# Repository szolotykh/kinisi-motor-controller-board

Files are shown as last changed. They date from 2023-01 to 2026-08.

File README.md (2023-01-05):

# Kinisi Motor Controller
Kinisi motor controller is based on STM32F405 microcontroller controller. The controller can control up to 4 brushed DC motors with encoders. It offers platform obstruction which is means user doesn’t need to control each individual motor form main computer, but rather it can control up to four motors as a whole by sending high level commands like set target speed or distance for a platform.

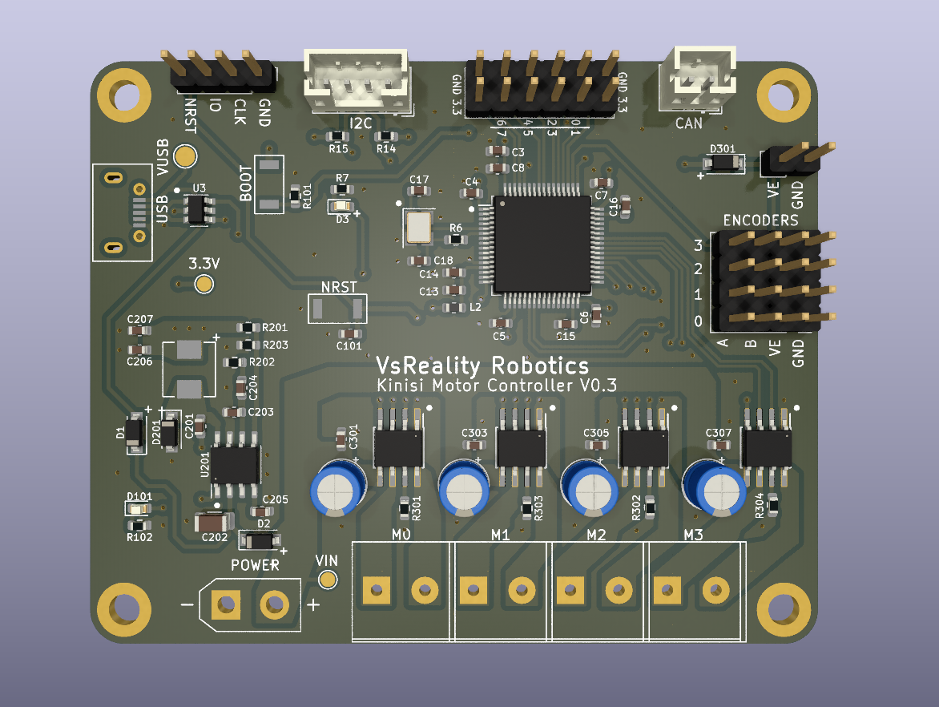
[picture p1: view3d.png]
Board 3d view


Features:
* Controls 4 motors
* Receives readings from 4 encoders
* Supports encoders with wide range of supply voltage (3.3V, 5V, custom) 

Interfaces:
* USB Serial device
* I2C
* CAN
* 4x GPIO

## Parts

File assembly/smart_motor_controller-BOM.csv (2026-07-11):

Comment | Designator | Footprint | LCSC
4u7 | C3 | Capacitor_SMD:C_0603_1608Metric | C19666
10uf | C202 | Capacitor_SMD:C_1206_3216Metric | C13585
1nF | C204 | Capacitor_SMD:C_0603_1608Metric | C340644
8.2nF | C205 | Capacitor_SMD:C_0603_1608Metric | C1322360
1u | C13,C101 | Capacitor_SMD:C_0603_1608Metric | C15849
10nf | C14,C203 | Capacitor_SMD:C_0603_1608Metric | C57112
2.2u | C15,C16 | Capacitor_SMD:C_0603_1608Metric | C23630
12p | C17,C18 | Capacitor_SMD:C_0603_1608Metric | C1642
47uF | C206,C207 | Capacitor_SMD:C_0603_1608Metric | C140782
100n | C301,C303,C305,C307 | Capacitor_SMD:C_0603_1608Metric | C14663
100nf | C4,C5,C6,C7,C8,C201 | Capacitor_SMD:C_0603_1608Metric | C694249
BLUE | D3 | LED_SMD:LED_0603_1608Metric | C193191
RED | D101 | LED_SMD:LED_0603_1608Metric | C84263
B5819W | D1,D2,D201,D301 | Diode_SMD:D_SOD-123 | C8598
16MHz | HSE1 | Crystal:Crystal_SMD_3225-4Pin_3.2x2.5mm | C13738
USB_B_Micro | J10 | VsReality_Footprints:U-F-M5DD-W-L | C145792
39n | L2 | Inductor_SMD:L_0603_1608Metric | C964035
10uH | L201 | Inductor_SMD:L_Sunlord_MWSA0518_5.4x5.2mm | C351099
47 | R6 | Resistor_SMD:R_0603_1608Metric | C1211
100 | R7 | Resistor_SMD:R_0603_1608Metric | C22775
120 | R102 | Resistor_SMD:R_0603_1608Metric | C22787
30K | R202 | Resistor_SMD:R_0603_1608Metric | C22984
3.3K | R203 | Resistor_SMD:R_0603_1608Metric | C269710
10K | R101,R201 | Resistor_SMD:R_0603_1608Metric | C116677
15 | R103,R104 | Resistor_SMD:R_0603_1608Metric | C22810
2k2 | R14,R15 | Resistor_SMD:R_0603_1608Metric | C4190
0.15 | R301,R302,R303,R304 | Resistor_SMD:R_0603_1608Metric | C45879
SW_NRST | SW102,SW103 | VsReality_Footprints:Diptronics MPTFP2-V-TR SMD 2.9x3.9x2mm | C495942
STM32F405RGT6 | U2 | Package_QFP:LQFP-64_10x10mm_P0.5mm | C15742
USBLC6-2SC6 | U3 | Package_TO_SOT_SMD:SOT-23-6 | C7519
TPS54331DDAR | U201 | Package_SO:HSOP-8-1EP_3.9x4.9mm_P1.27mm_EP2.41x3.1mm_ThermalVias | C90761
DRV8870DDA | U301,U302,U303,U304 | Package_SO:Texas_HTSOP-8-1EP_3.9x4.9mm_P1.27mm_EP2.95x4.9mm_Mask2.4x3.1mm_ThermalVias | C86590

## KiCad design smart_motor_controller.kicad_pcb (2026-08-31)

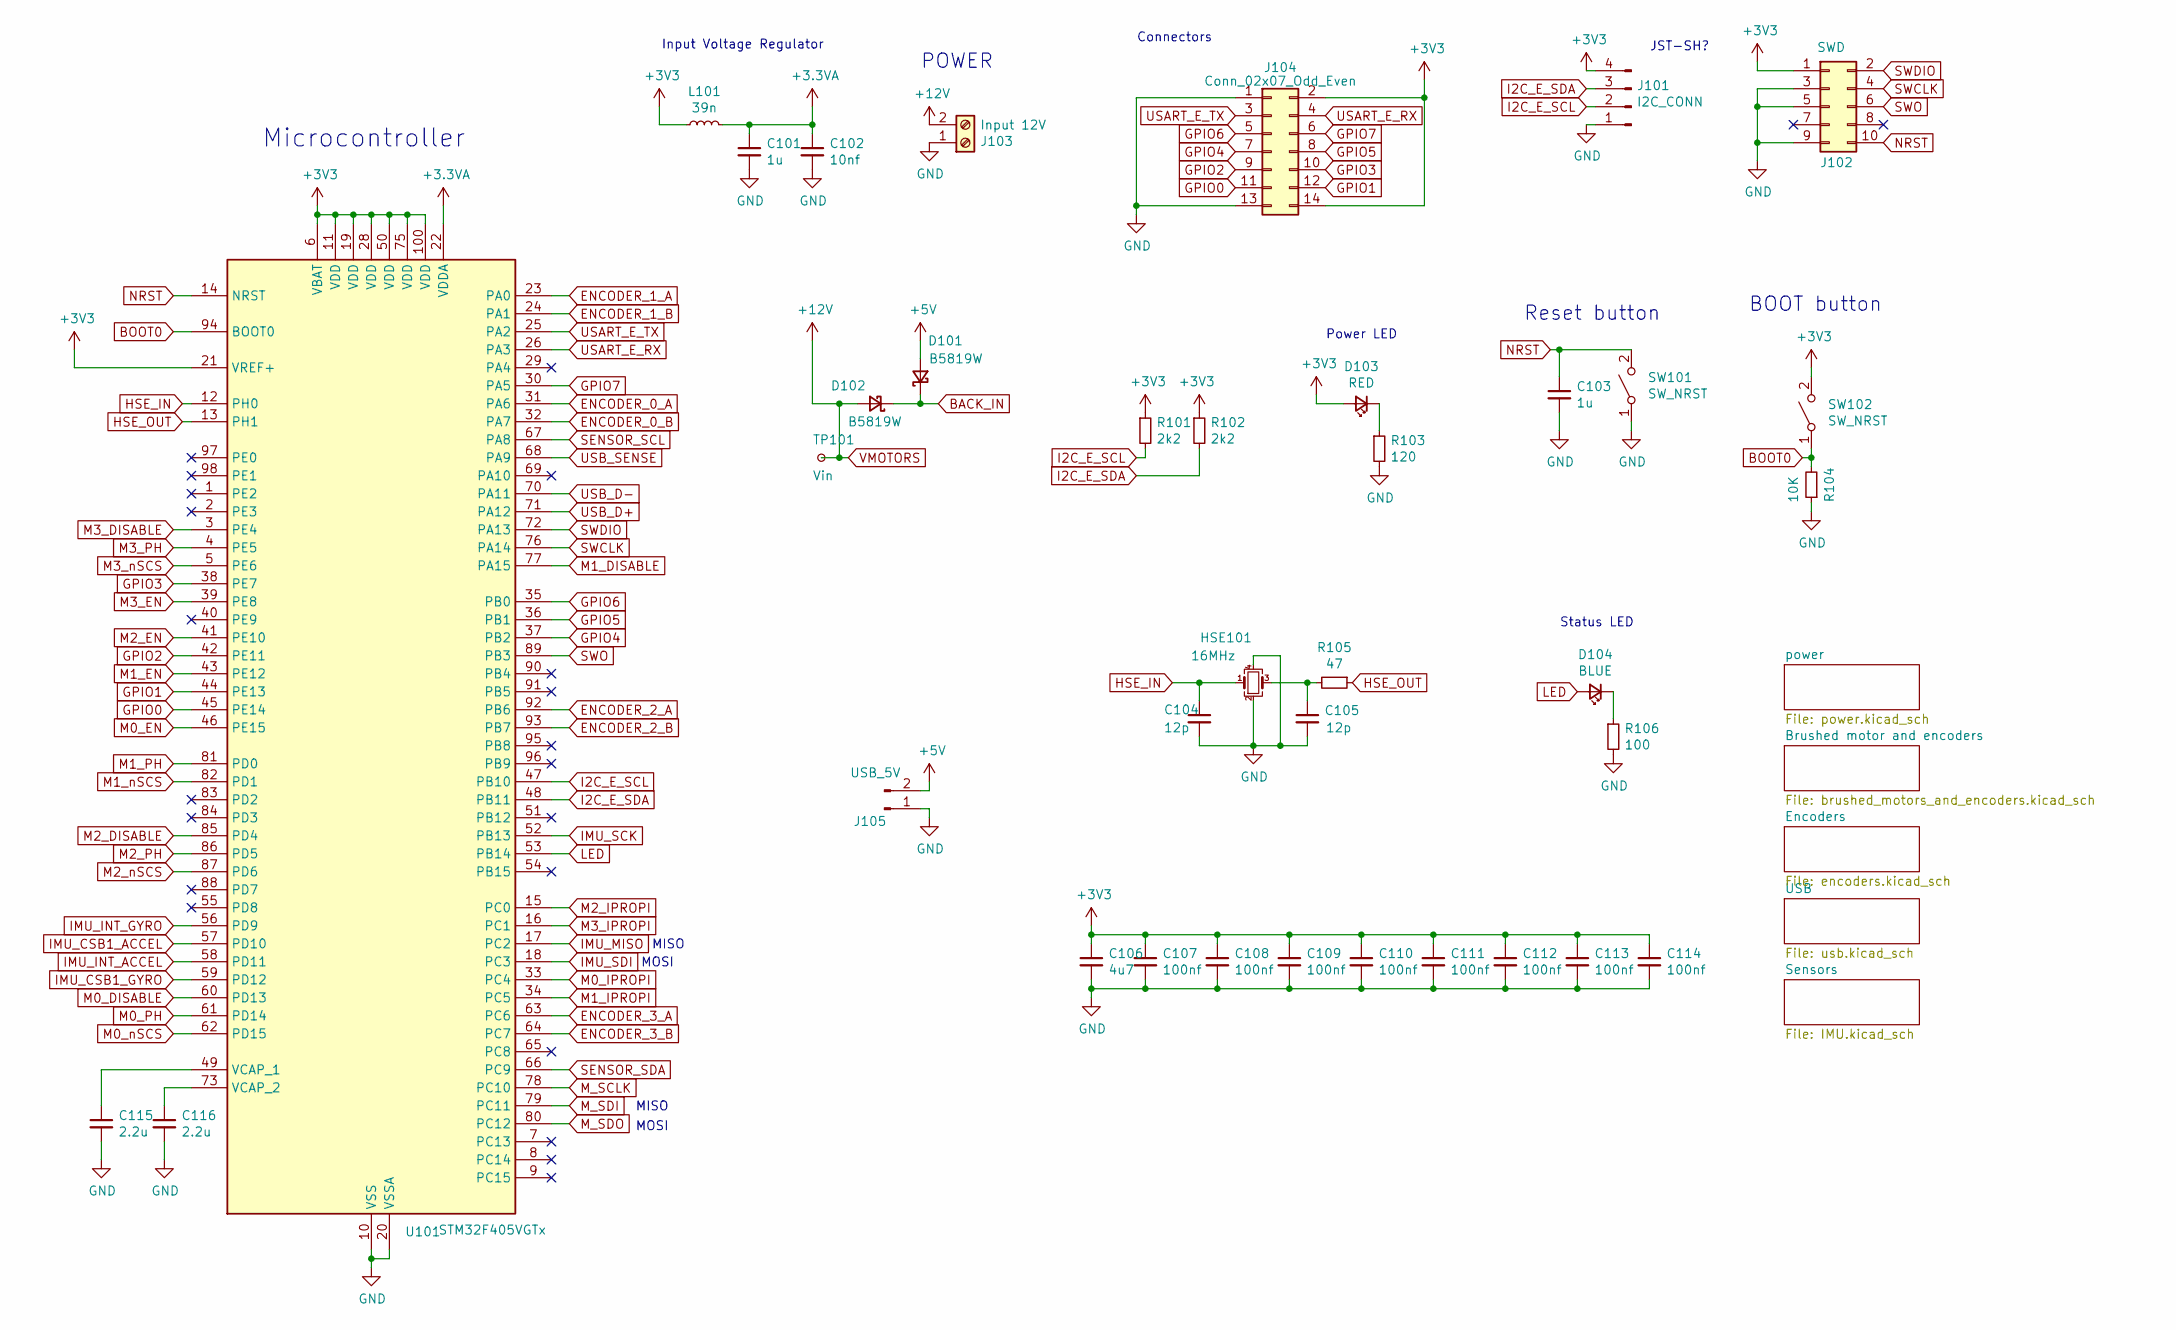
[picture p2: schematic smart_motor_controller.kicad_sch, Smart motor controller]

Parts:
C101, C103: 1u; C_0603_1608Metric; LCSC Part # C15849
C102: 10nf; C_0603_1608Metric; LCSC Part # C57112
C104, C105: 12p; C_0603_1608Metric; LCSC Part # C1642
C106: 4u7; C_0603_1608Metric; LCSC Part # C19666
C107, C108, C109, C110, C111, C112, C113, C114: 100nf; C_0603_1608Metric; LCSC Part # C694249
C115, C116: 2.2u; C_0603_1608Metric; LCSC Part # C23630
D101, D102: B5819W; D_SOD-123; LCSC Part # C8598
D103: RED; LED_0603_1608Metric; LCSC Part # C84263
D104: BLUE; LED_0603_1608Metric; LCSC Part # C193191
HSE101: 16MHz; Crystal_SMD_3225-4Pin_3.2x2.5mm; LCSC Part # C13738
J101: I2C_CONN; JST_PH_B4B-PH-K_1x04_P2.00mm_Vertical
J102: SWD; PinHeader_2x05_P1.27mm_Vertical
J103: Input 12V; AMASS_XT30UPB-M_1x02_P5.0mm_Vertical
J104: Conn_02x07_Odd_Even; PinHeader_2x07_P2.54mm_Vertical
J105: USB_5V; PinHeader_2x01_P2.54mm_Vertical
L101: 39n; L_0603_1608Metric; LCSC Part # C964035
R101, R102: 2k2; R_0603_1608Metric; LCSC Part # C4190
R103: 120; R_0603_1608Metric; LCSC Part # C22787
R104: 10K; R_0603_1608Metric; LCSC Part # C116677
R105: 47; R_0603_1608Metric; LCSC Part # C1211
R106: 100; R_0603_1608Metric; LCSC Part # C22775
SW101, SW102: SW_NRST; Diptronics MPTFP2-V-TR SMD 2.9x3.9x2mm; LCSC Part # C495942
TP101: Vin; TestPoint_Pad_D1.5mm
U101: STM32F405VGTx; LQFP-100_14x14mm_P0.5mm

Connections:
+3.3VA: C101.1, C102.1, L101.2, U101.22 (VDDA)
+3V3: C106.1, C107.1, C108.1, C109.1, C110.1, C111.1, C112.1, C113.1, C114.1, D103.2 (A), J101.4, J102.1, J104.2, J104.14, L101.1, R101.1, R102.1, SW102.2 (B), U101.6 (VBAT), U101.11 (VDD), U101.19 (VDD), U101.21 (VREF+), U101.28 (VDD), U101.50 (VDD), U101.75 (VDD), U101.100 (VDD); also elsewhere on the board
+5V: D101.2 (A), J105.2; also elsewhere on the board
BACK_IN: D101.1 (K), D102.1 (K); also elsewhere on the board
BOOT0: R104.2, SW102.1 (A), U101.94 (BOOT0)
ENCODER_0_A: U101.31 (PA6); also elsewhere on the board
ENCODER_0_B: U101.32 (PA7); also elsewhere on the board
ENCODER_1_A: U101.23 (PA0); also elsewhere on the board
ENCODER_1_B: U101.24 (PA1); also elsewhere on the board
ENCODER_2_A: U101.92 (PB6); also elsewhere on the board
ENCODER_2_B: U101.93 (PB7); also elsewhere on the board
ENCODER_3_A: U101.63 (PC6); also elsewhere on the board
ENCODER_3_B: U101.64 (PC7); also elsewhere on the board
GND: C101.2, C102.2, C103.2, C104.2, C105.2, C106.2, C107.2, C108.2, C109.2, C110.2, C111.2, C112.2, C113.2, C114.2, C115.2, C116.2, HSE101.2, HSE101.4, J101.1, J102.3, J102.5, J102.9, J103.1, J104.1, J104.13, J105.1, R103.2, R104.1, R106.2, SW101.1 (A), U101.10 (VSS), U101.20 (VSSA), U101.27 (VSS), U101.74 (VSS), U101.99 (VSS); also elsewhere on the board
GPIO0: J104.11, U101.45 (PE14)
GPIO1: J104.12, U101.44 (PE13)
GPIO2: J104.9, U101.42 (PE11)
GPIO3: J104.10, U101.38 (PE7)
GPIO4: J104.7, U101.37 (PB2)
GPIO5: J104.8, U101.36 (PB1)
GPIO6: J104.5, U101.35 (PB0)
GPIO7: J104.6, U101.30 (PA5)
HSE_IN: C104.1, HSE101.1, U101.12 (PH0)
HSE_OUT: R105.1, U101.13 (PH1)
I2C_E_SCL: J101.2, R101.2, U101.47 (PB10)
I2C_E_SDA: J101.3, R102.2, U101.48 (PB11)
IMU_CSB1_ACCEL: U101.57 (PD10); also elsewhere on the board
IMU_CSB1_GYRO: U101.59 (PD12); also elsewhere on the board
IMU_INT_ACCEL: U101.58 (PD11); also elsewhere on the board
IMU_INT_GYRO: U101.56 (PD9); also elsewhere on the board
IMU_MISO: U101.17 (PC2); also elsewhere on the board
IMU_SCK: U101.52 (PB13); also elsewhere on the board
IMU_SDI: U101.18 (PC3); also elsewhere on the board
LED: D104.2 (A), U101.53 (PB14)
M0_DISABLE: U101.60 (PD13); also elsewhere on the board
M0_EN: U101.46 (PE15); also elsewhere on the board
M0_IPROPI: U101.33 (PC4); also elsewhere on the board
M0_PH: U101.61 (PD14); also elsewhere on the board
M0_nSCS: U101.62 (PD15); also elsewhere on the board
M1_DISABLE: U101.77 (PA15); also elsewhere on the board
M1_EN: U101.43 (PE12); also elsewhere on the board
M1_IPROPI: U101.34 (PC5); also elsewhere on the board
M1_PH: U101.81 (PD0); also elsewhere on the board
M1_nSCS: U101.82 (PD1); also elsewhere on the board
M2_DISABLE: U101.85 (PD4); also elsewhere on the board
M2_EN: U101.41 (PE10); also elsewhere on the board
M2_IPROPI: U101.15 (PC0); also elsewhere on the board
M2_PH: U101.86 (PD5); also elsewhere on the board
M2_nSCS: U101.87 (PD6); also elsewhere on the board
M3_DISABLE: U101.3 (PE4); also elsewhere on the board
M3_EN: U101.39 (PE8); also elsewhere on the board
M3_IPROPI: U101.16 (PC1); also elsewhere on the board
M3_PH: U101.4 (PE5); also elsewhere on the board
M3_nSCS: U101.5 (PE6); also elsewhere on the board
M_SCLK: U101.78 (PC10); also elsewhere on the board
M_SDI: U101.79 (PC11); also elsewhere on the board
M_SDO: U101.80 (PC12); also elsewhere on the board
NRST: C103.1, J102.10, SW101.2 (B), U101.14 (NRST); also elsewhere on the board
unnamed: C105.1, HSE101.3, R105.2
unnamed: D103.1 (K), R103.1
unnamed: D104.1 (K), R106.1
unnamed: C115.1, U101.49 (VCAP_1)
unnamed: C116.1, U101.73 (VCAP_2)
SENSOR_SCL: U101.67 (PA8); also elsewhere on the board
SENSOR_SDA: U101.66 (PC9); also elsewhere on the board
SWCLK: J102.4, U101.76 (PA14); also elsewhere on the board
SWDIO: J102.2, U101.72 (PA13); also elsewhere on the board
SWO: J102.6, U101.89 (PB3); also elsewhere on the board
USART_E_RX: J104.4, U101.26 (PA3)
USART_E_TX: J104.3, U101.25 (PA2)
USB_D+: U101.71 (PA12); also elsewhere on the board
USB_D-: U101.70 (PA11); also elsewhere on the board
USB_SENSE: U101.68 (PA9); also elsewhere on the board
VMOTORS: D102.2 (A), J103.2, TP101.1; also elsewhere on the board

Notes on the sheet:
MISO
Reset button
Input Voltage Regulator
Status LED
POWER
BOOT button
MOSI
Connectors
Power LED
JST-SH?
Microcontroller

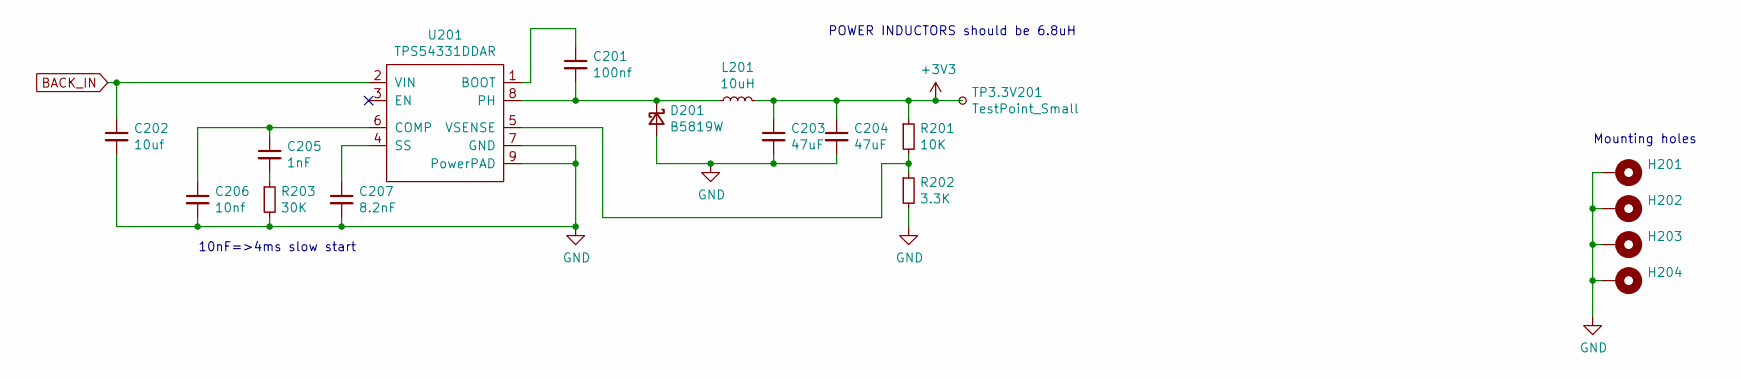
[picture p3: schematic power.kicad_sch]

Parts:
C201: 100nf; C_0603_1608Metric; LCSC Part # C694249
C202: 10uf; C_1206_3216Metric; LCSC Part # C13585
C203, C204: 47uF; C_0603_1608Metric; LCSC Part # C140782
C205: 1nF; C_0603_1608Metric; LCSC Part # C340644
C206: 10nf; C_0603_1608Metric; LCSC Part # C57112
C207: 8.2nF; C_0603_1608Metric; LCSC Part # C1322360
D201: B5819W; D_SOD-123; LCSC Part # C8598
H201, H202, H203, H204: MountingHole_Pad; MountingHole_3.2mm_M3_DIN965_Pad
L201: 10uH; L_Sunlord_MWSA0518_5.4x5.2mm; LCSC Part # C351099
R201: 10K; R_0603_1608Metric; LCSC Part # C116677
R202: 3.3K; R_0603_1608Metric; LCSC Part # C269710
R203: 30K; R_0603_1608Metric; LCSC Part # C22984
TP3.3V201: TestPoint_Small; TestPoint_Pad_D1.5mm
U201: TPS54331DDAR; HSOP-8-1EP_3.9x4.9mm_P1.27mm_EP2.41x3.1mm_ThermalVias; LCSC Part # C90761

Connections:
+3V3: C203.1, C204.1, L201.2, R201.1, TP3.3V201.1; also elsewhere on the board
BACK_IN: C202.1, U201.2 (VIN); also elsewhere on the board
GND: C202.2, C203.2, C204.2, C206.2, C207.2, D201.2 (A), H201.1, H202.1, H203.1, H204.1, R202.2, R203.2, U201.7 (GND), U201.9 (PowerPAD); also elsewhere on the board
unnamed: C205.2, R203.1
unnamed: C201.2, D201.1 (K), L201.1, U201.8 (PH)
unnamed: C201.1, U201.1 (BOOT)
unnamed: C205.1, C206.1, U201.6 (COMP)
unnamed: C207.1, U201.4 (SS)
unnamed: R201.2, R202.1, U201.5 (VSENSE)

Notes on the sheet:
Mounting holes
POWER INDUCTORS should be 6.8uH
10nF=>4ms slow start

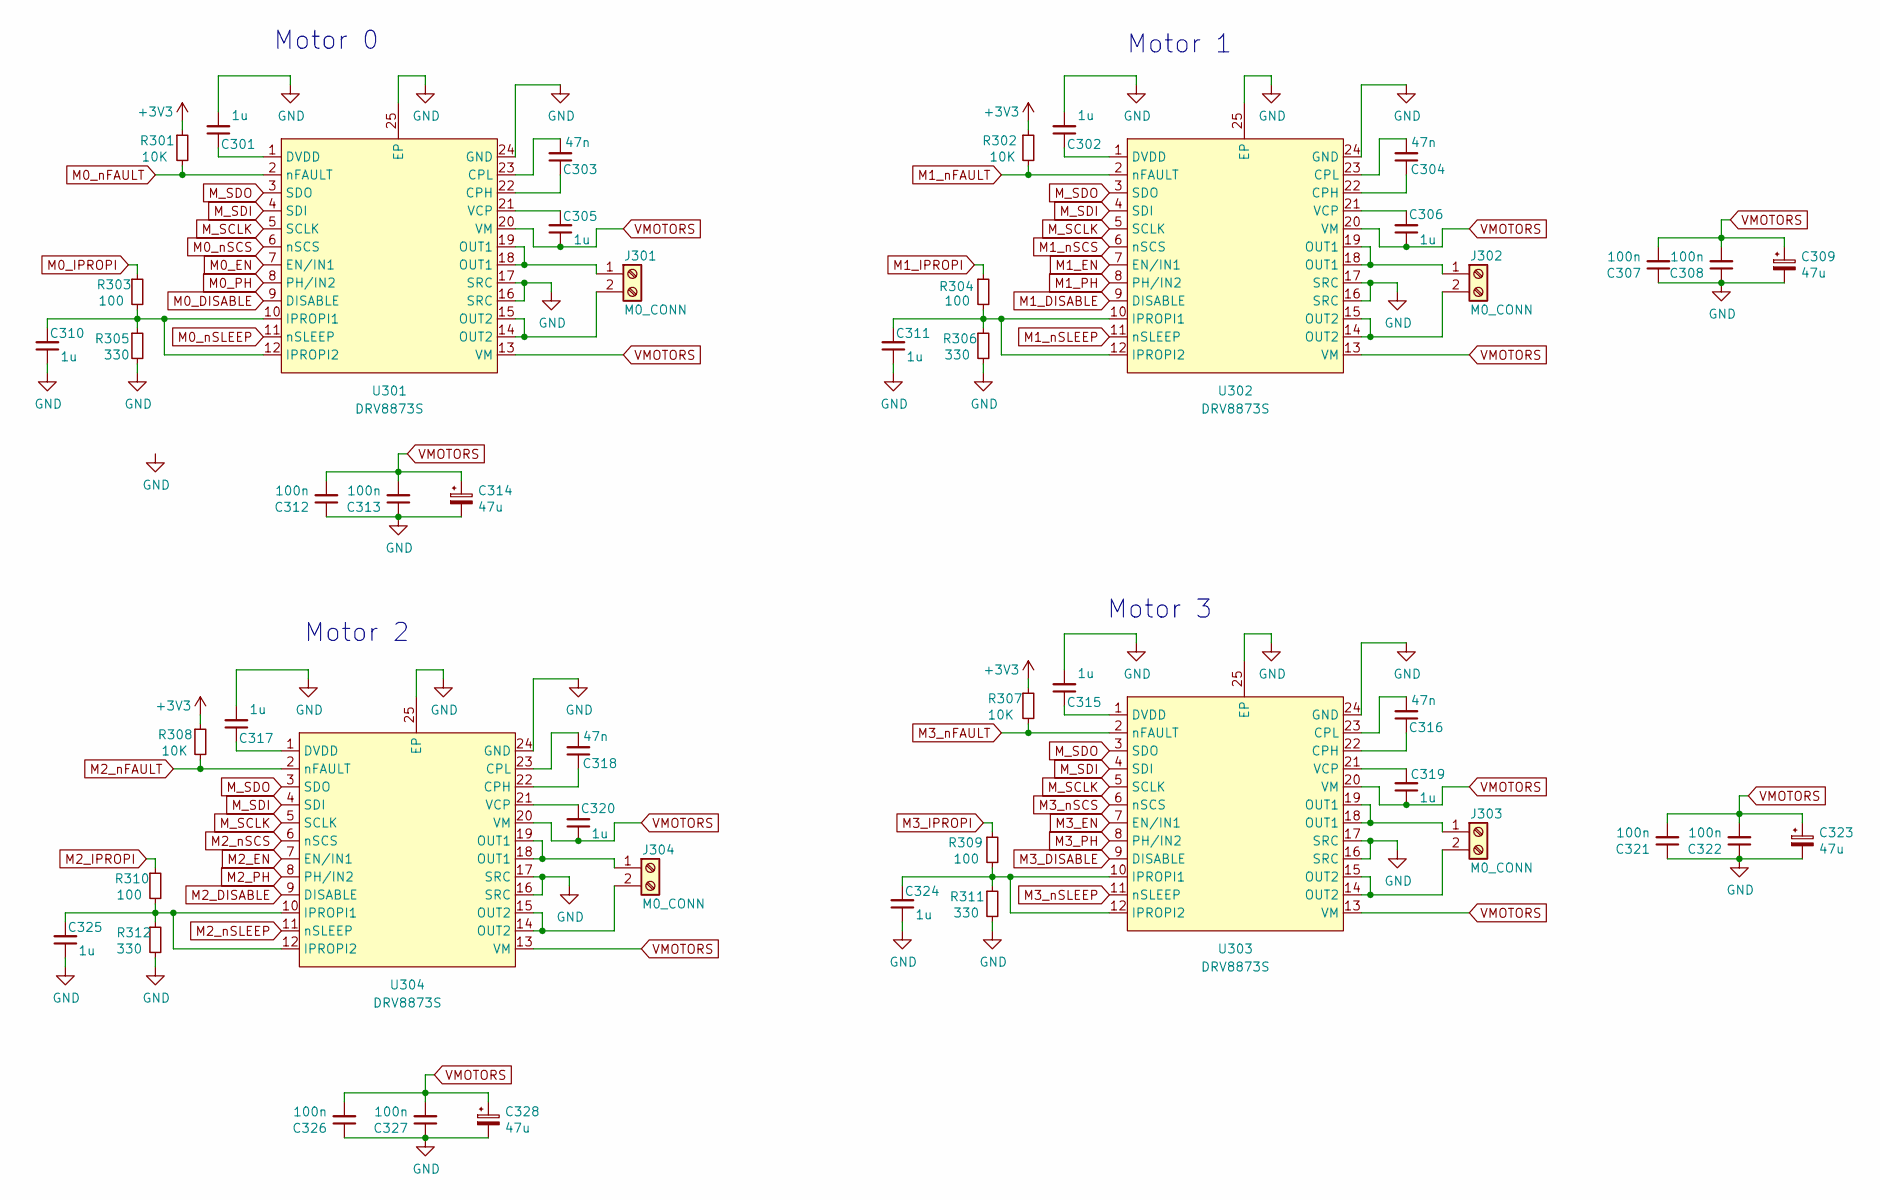
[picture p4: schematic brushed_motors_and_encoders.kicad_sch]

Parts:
C301, C302, C305, C306, C310, C311, C315, C317, C319, C320, C324, C325: 1u; C_0603_1608Metric
C303, C304, C316, C318: 47n; C_0603_1608Metric
C307, C308, C312, C313, C321, C322, C326, C327: 100n; C_0603_1608Metric; LCSC Part # C14663
C309, C314, C323, C328: 47u; CP_Radial_D5.0mm_P2.00mm
J301, J302, J303, J304: M0_CONN; Ningbo_Kangnex_Elec_WJ128V_5_0_2P
R301, R302, R307, R308: 10K; R_0603_1608Metric
R303, R304, R309, R310: 100; R_0603_1608Metric
R305, R306, R311, R312: 330; R_0603_1608Metric
U301, U302, U303, U304: DRV8873S; HTSSOP-24_L7.8-W4.4-P0.65-LS6.4-TL-EP; LCSC Part # C2150662

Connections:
+3V3: R301.1, R302.1, R307.1, R308.1; also elsewhere on the board
GND: C301.2, C302.2, C307.1, C308.1, C309.2, C310.1, C311.1, C312.1, C313.1, C314.2, C315.2, C317.2, C321.1, C322.1, C323.2, C324.1, C325.1, C326.1, C327.1, C328.2, R305.2, R306.2, R311.2, R312.2, U301.16 (SRC), U301.17 (SRC), U301.24 (GND), U301.25 (EP), U302.16 (SRC), U302.17 (SRC), U302.24 (GND), U302.25 (EP), U303.16 (SRC), U303.17 (SRC), U303.24 (GND), U303.25 (EP), U304.16 (SRC), U304.17 (SRC), U304.24 (GND), U304.25 (EP); also elsewhere on the board
M0_DISABLE: U301.9 (DISABLE); also elsewhere on the board
M0_EN: U301.7 (EN/IN1); also elsewhere on the board
M0_IPROPI: R303.1; also elsewhere on the board
M0_PH: U301.8 (PH/IN2); also elsewhere on the board
M0_nFAULT: R301.2, U301.2 (nFAULT)
M0_nSCS: U301.6 (nSCS); also elsewhere on the board
M0_nSLEEP: U301.11 (nSLEEP)
M1_DISABLE: U302.9 (DISABLE); also elsewhere on the board
M1_EN: U302.7 (EN/IN1); also elsewhere on the board
M1_IPROPI: R304.1; also elsewhere on the board
M1_PH: U302.8 (PH/IN2); also elsewhere on the board
M1_nFAULT: R302.2, U302.2 (nFAULT)
M1_nSCS: U302.6 (nSCS); also elsewhere on the board
M1_nSLEEP: U302.11 (nSLEEP)
M2_DISABLE: U304.9 (DISABLE); also elsewhere on the board
M2_EN: U304.7 (EN/IN1); also elsewhere on the board
M2_IPROPI: R310.1; also elsewhere on the board
M2_PH: U304.8 (PH/IN2); also elsewhere on the board
M2_nFAULT: R308.2, U304.2 (nFAULT)
M2_nSCS: U304.6 (nSCS); also elsewhere on the board
M2_nSLEEP: U304.11 (nSLEEP)
M3_DISABLE: U303.9 (DISABLE); also elsewhere on the board
M3_EN: U303.7 (EN/IN1); also elsewhere on the board
M3_IPROPI: R309.1; also elsewhere on the board
M3_PH: U303.8 (PH/IN2); also elsewhere on the board
M3_nFAULT: R307.2, U303.2 (nFAULT)
M3_nSCS: U303.6 (nSCS); also elsewhere on the board
M3_nSLEEP: U303.11 (nSLEEP)
M_SCLK: U301.5 (SCLK), U302.5 (SCLK), U303.5 (SCLK), U304.5 (SCLK); also elsewhere on the board
M_SDI: U301.4 (SDI), U302.4 (SDI), U303.4 (SDI), U304.4 (SDI); also elsewhere on the board
M_SDO: U301.3 (SDO), U302.3 (SDO), U303.3 (SDO), U304.3 (SDO); also elsewhere on the board
unnamed: J301.1, U301.18 (OUT1), U301.19 (OUT1)
unnamed: J301.2, U301.14 (OUT2), U301.15 (OUT2)
unnamed: J302.1, U302.18 (OUT1), U302.19 (OUT1)
unnamed: J302.2, U302.14 (OUT2), U302.15 (OUT2)
unnamed: J303.1, U303.18 (OUT1), U303.19 (OUT1)
unnamed: J303.2, U303.14 (OUT2), U303.15 (OUT2)
unnamed: J304.1, U304.18 (OUT1), U304.19 (OUT1)
unnamed: J304.2, U304.14 (OUT2), U304.15 (OUT2)
unnamed: C303.1, U301.22 (CPH)
unnamed: C303.2, U301.23 (CPL)
unnamed: C301.1, U301.1 (DVDD)
unnamed: C310.2, R303.2, R305.1, U301.10 (IPROPI1), U301.12 (IPROPI2)
unnamed: C305.2, U301.21 (VCP)
unnamed: C304.1, U302.22 (CPH)
unnamed: C304.2, U302.23 (CPL)
unnamed: C302.1, U302.1 (DVDD)
unnamed: C311.2, R304.2, R306.1, U302.10 (IPROPI1), U302.12 (IPROPI2)
unnamed: C306.2, U302.21 (VCP)
unnamed: C316.1, U303.22 (CPH)
unnamed: C316.2, U303.23 (CPL)
unnamed: C315.1, U303.1 (DVDD)
unnamed: C324.2, R309.2, R311.1, U303.10 (IPROPI1), U303.12 (IPROPI2)
unnamed: C319.2, U303.21 (VCP)
unnamed: C318.1, U304.22 (CPH)
unnamed: C318.2, U304.23 (CPL)
unnamed: C317.1, U304.1 (DVDD)
unnamed: C325.2, R310.2, R312.1, U304.10 (IPROPI1), U304.12 (IPROPI2)
unnamed: C320.2, U304.21 (VCP)
VMOTORS: C305.1, C306.1, C307.2, C308.2, C309.1, C312.2, C313.2, C314.1, C319.1, C320.1, C321.2, C322.2, C323.1, C326.2, C327.2, C328.1, U301.13 (VM), U301.20 (VM), U302.13 (VM), U302.20 (VM), U303.13 (VM), U303.20 (VM), U304.13 (VM), U304.20 (VM); also elsewhere on the board

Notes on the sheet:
Motor 2
Motor 1
Motor 3
Motor 0

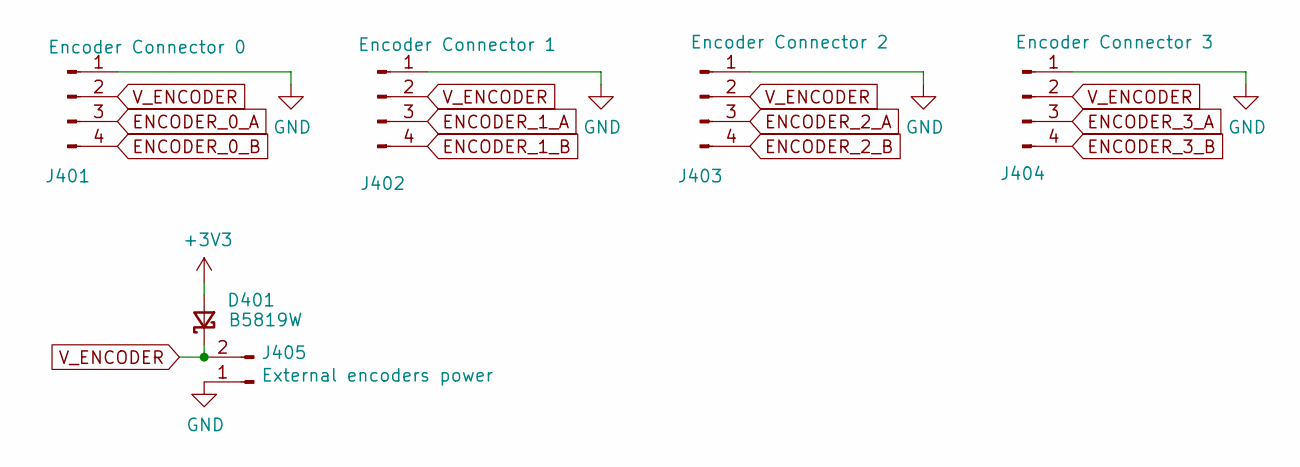
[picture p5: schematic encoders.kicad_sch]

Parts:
D401: B5819W; D_SOD-123; LCSC Part # C8598
J401: Encoder Connector 0; JST_PH_B4B-PH-K_1x04_P2.00mm_Vertical
J402: Encoder Connector 1; JST_PH_B4B-PH-K_1x04_P2.00mm_Vertical
J403: Encoder Connector 2; JST_PH_B4B-PH-K_1x04_P2.00mm_Vertical
J404: Encoder Connector 3; JST_PH_B4B-PH-K_1x04_P2.00mm_Vertical
J405: External encoders power; PinHeader_1x02_P2.54mm_Vertical

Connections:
+3V3: D401.2 (A); also elsewhere on the board
GND: J401.1, J402.1, J403.1, J404.1, J405.1; also elsewhere on the board
V_ENCODER: D401.1 (K), J401.2, J402.2, J403.2, J404.2, J405.2; also elsewhere on the board

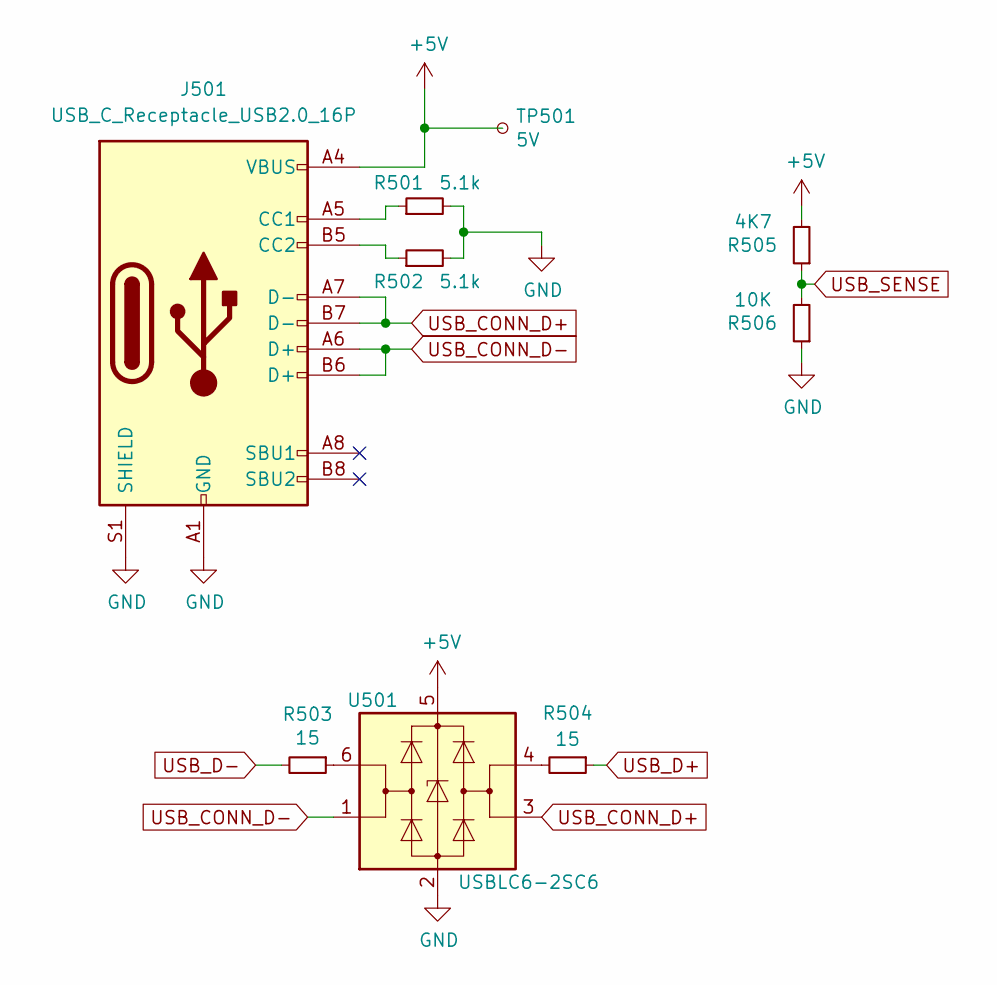
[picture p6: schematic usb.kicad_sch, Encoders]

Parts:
J501: USB_C_Receptacle_USB2.0_16P; USB_C_Receptacle_GCT_USB4105-xx-A_16P_TopMnt_Horizontal
R501, R502: 5.1k; R_0603_1608Metric
R503, R504: 15; R_0603_1608Metric; LCSC Part # C25118
R505: 4K7; R_0603_1608Metric
R506: 10K; R_0603_1608Metric
TP501: 5V; TestPoint_Pad_D2.0mm
U501: USBLC6-2SC6; SOT-23-6; LCSC Part # C7519

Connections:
+5V: J501.A4 (VBUS), J501.A9 (VBUS), J501.B4 (VBUS), J501.B9 (VBUS), R505.2, TP501.1, U501.5 (VBUS); also elsewhere on the board
GND: J501.A1 (GND), J501.A12 (GND), J501.B1 (GND), J501.B12 (GND), J501.S1 (SHIELD), R501.2, R502.2, R506.1, U501.2 (GND); also elsewhere on the board
unnamed: J501.A5 (CC1), R501.1
unnamed: J501.B5 (CC2), R502.1
unnamed: R503.1, U501.6 (I/O1)
unnamed: R504.2, U501.4 (I/O2)
USB_CONN_D+: J501.A7 (D-), J501.B7 (D-), U501.3 (I/O2)
USB_CONN_D-: J501.A6 (D+), J501.B6 (D+), U501.1 (I/O1)
USB_D+: R504.1; also elsewhere on the board
USB_D-: R503.2; also elsewhere on the board
USB_SENSE: R505.1, R506.2; also elsewhere on the board

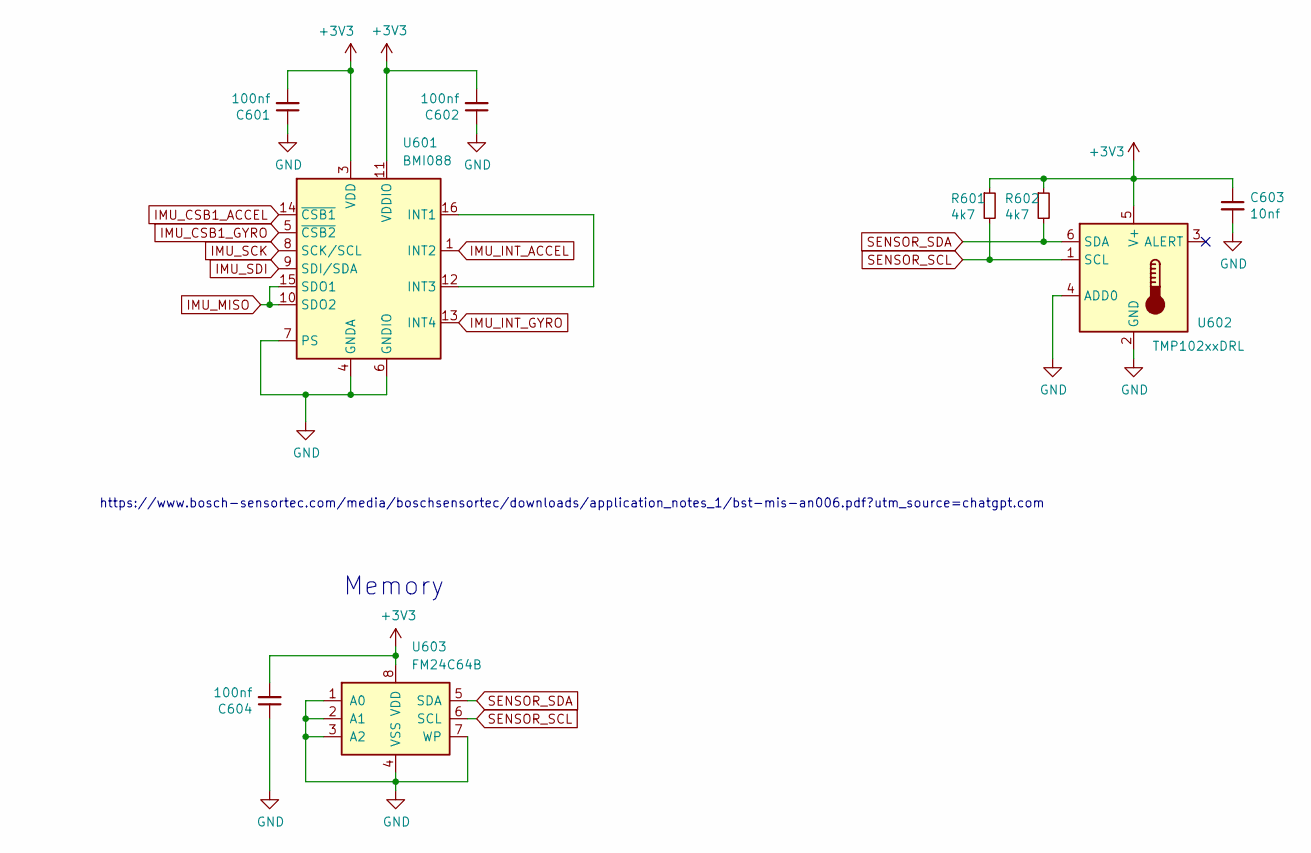
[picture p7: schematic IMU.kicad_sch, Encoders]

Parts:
C601, C602, C604: 100nf; C_0603_1608Metric
C603: 10nf; C_0603_1608Metric; LCSC Part # C57112
R601, R602: 4k7; R_0603_1608Metric
U601: BMI088; Bosch_LGA-16_4.5x3mm_P0.5mm_LayoutBorder7x1y_ClockwisePinNu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
U602: TMP102xxDRL; SOT-563
U603: FM24C64B; SOIC-8_3.9x4.9mm_P1.27mm

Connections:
+3V3: C601.2, C602.2, C603.1, C604.2, R601.1, R602.1, U601.3 (VDD), U601.11 (VDDIO), U602.5 (V+), U603.8 (VDD); also elsewhere on the board
GND: C601.1, C602.1, C603.2, C604.1, U601.2 (GNDA), U601.4 (GNDA), U601.6 (GNDIO), U601.7 (PS), U602.2 (GND), U602.4 (ADD0), U603.1 (A0), U603.2 (A1), U603.3 (A2), U603.4 (VSS), U603.7 (WP); also elsewhere on the board
IMU_CSB1_ACCEL: U601.14 (~CSB1); also elsewhere on the board
IMU_CSB1_GYRO: U601.5 (~CSB2); also elsewhere on the board
IMU_INT_ACCEL: U601.1 (INT2); also elsewhere on the board
IMU_INT_GYRO: U601.13 (INT4); also elsewhere on the board
IMU_MISO: U601.10 (SDO2), U601.15 (SDO1); also elsewhere on the board
IMU_SCK: U601.8 (SCK/SCL); also elsewhere on the board
IMU_SDI: U601.9 (SDI/SDA); also elsewhere on the board
unnamed: U601.12 (INT3), U601.16 (INT1)
SENSOR_SCL: R601.2, U602.1 (SCL), U603.6 (SCL); also elsewhere on the board
SENSOR_SDA: R602.2, U602.6 (SDA), U603.5 (SDA); also elsewhere on the board

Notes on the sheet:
Memory
https://www.bosch-sensortec.com/media/boschsensortec/downloads/application_notes_1/bst-mis-an006.pdf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

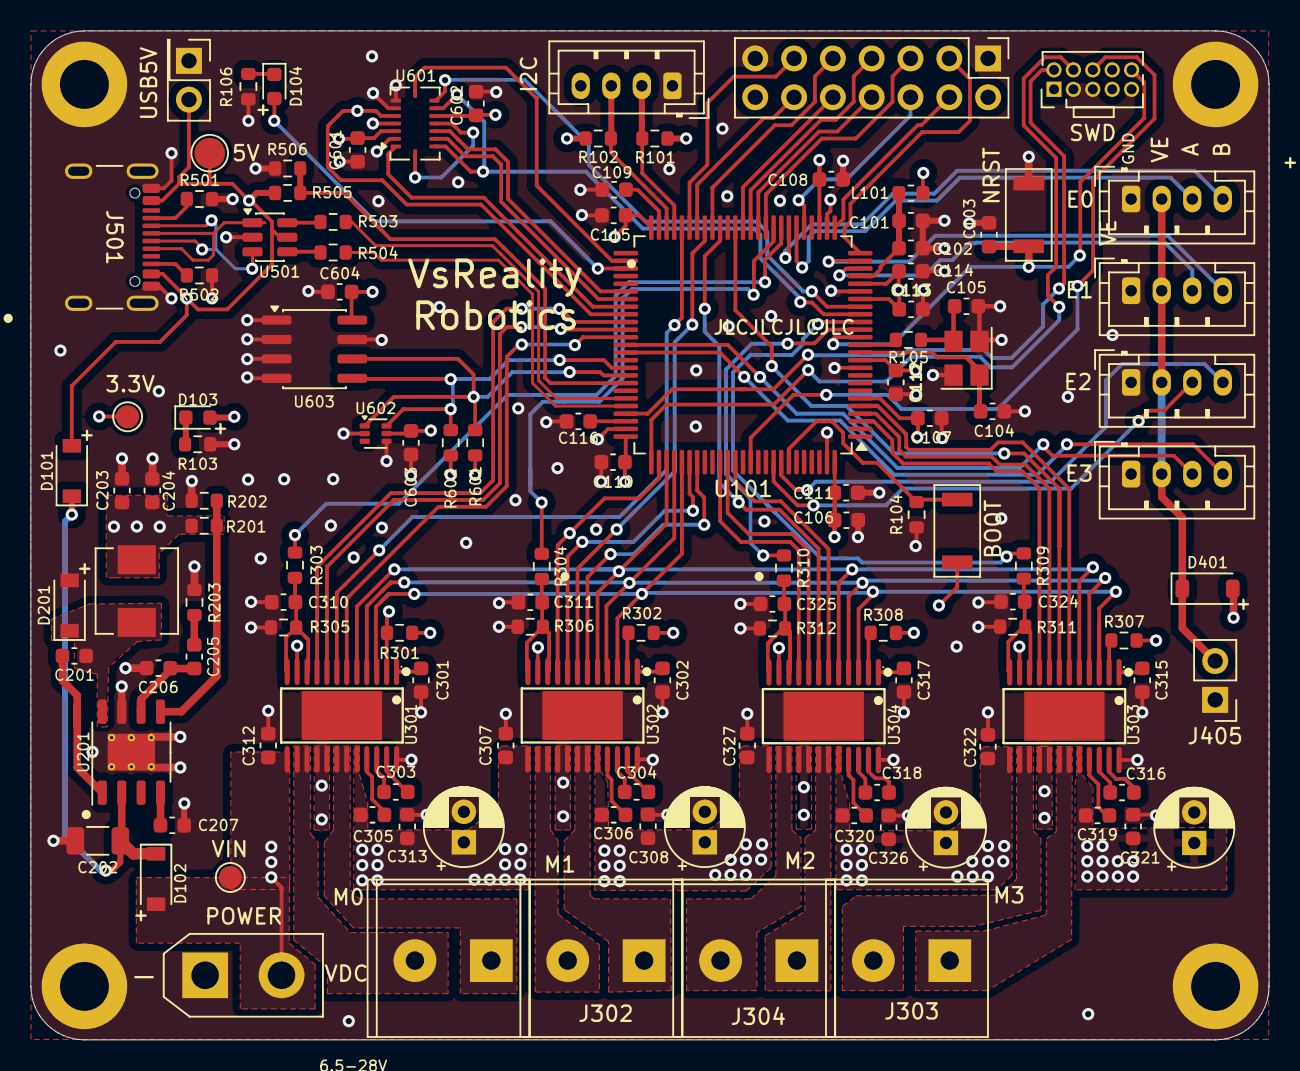
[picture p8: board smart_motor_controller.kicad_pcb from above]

Board: 4 copper layers, 81.0 x 66.0 mm, 127 parts (0 on the bottom side), 120 nets.

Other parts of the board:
5V: 5V; TestPoint_Pad_D2.0mm
E0: Encoder Connector 0; JST_PH_B4B-PH-K_1x04_P2.00mm_Vertical
E1: Encoder Connector 1; JST_PH_B4B-PH-K_1x04_P2.00mm_Vertical
E2: Encoder Connector 2; JST_PH_B4B-PH-K_1x04_P2.00mm_Vertical
E3: Encoder Connector 3; JST_PH_B4B-PH-K_1x04_P2.00mm_Vertical
SWD: SWD; PinHeader_2x05_P1.27mm_Vertical
USB5V: USB_5V; PinHeader_2x01_P2.54mm_Vertical

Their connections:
+3V3: SWD.1; also elsewhere on the board
+5V: 5V.1, USB5V.2; also elsewhere on the board
ENCODER_0_A: E0.3; also elsewhere on the board
ENCODER_0_B: E0.4; also elsewhere on the board
ENCODER_1_A: E1.3; also elsewhere on the board
ENCODER_1_B: E1.4; also elsewhere on the board
ENCODER_2_A: E2.3; also elsewhere on the board
ENCODER_2_B: E2.4; also elsewhere on the board
ENCODER_3_A: E3.3; also elsewhere on the board
ENCODER_3_B: E3.4; also elsewhere on the board
GND: E0.1, E1.1, E2.1, E3.1, SWD.3, SWD.5, SWD.9, USB5V.1; also elsewhere on the board
NRST: SWD.10; also elsewhere on the board
SWCLK: SWD.4; also elsewhere on the board
SWDIO: SWD.2; also elsewhere on the board
SWO: SWD.6; also elsewhere on the board
V_ENCODER: E0.2, E1.2, E2.2, E3.2; also elsewhere on the board

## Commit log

2021-03-15 Finish routing
    [smart_motor_controller.kicad_pcb, smart_motor_controller.sch]
2021-03-21 v0.1 Original design
    [smart_motor_controller.kicad_pcb, smart_motor_controller.sch]
2021-03-25 V0.1.1 Removed fuse and AO3401A
    [smart_motor_controller.kicad_pcb, smart_motor_controller.sch]
2021-04-01 Add assembly and gerber files
    [smart_motor_controller-BOM.csv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]
2021-05-27 First draft
    [brushed_motors_and_encoders.sch, power.sch, smart_motor_controller.kicad_pcb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]
2022-03-18 Additional changes
    [power.sch, smart_motor_controller-BOM.csv, smart_motor_controller-BOM.xlsx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]
2022-03-26 Change footprint for a comonent
    [brushed_motors_and_encoders.sch, power.sch, smart_motor_controller.kicad_pcb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]
2022-03-26 Update manufacturing files
    [smart_motor_controller-BOM.csv, smart_motor_controller-BOM.xlsx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]
2022-03-29 Fixed issue with diodes
    [smart_motor_controller-BOM.csv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]
2022-06-13 Change in FDD6685
    [smart_motor_controller.kicad_pcb, smart_motor_controller.sch]
2022-06-18 Update labels on the board
    [smart_motor_controller.kicad_pcb]
2023-04-01 Initial update
    [brushed_motors_and_encoders.kicad_sch, power.kicad_sch, smart_motor_controller.kicad_pcb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]
2023-04-03 Edge of the bpard
    [power.kicad_sch, smart_motor_controller.kicad_pcb]
2023-04-22 Change components to 0603
    [power.kicad_sch, smart_motor_controller.kicad_pcb, smart_motor_controller.kicad_sch]
2023-04-23 Reorganized motor drivers
    [smart_motor_controller.kicad_pcb, smart_motor_controller.kicad_sch]
2023-04-30 Complete layout
    [smart_motor_controller.kicad_pcb, smart_motor_controller.kicad_sch]
2023-08-08 Updated gedber files
    [brushed_motors_and_encoders.kicad_sch, power.kicad_sch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]
2026-06-29 Add CLAUDE.md for repository guidance and design documentation
    - Introduced CLAUDE.md to provide an overview of the Kinisi smart motor controller board design.
    - Included details on editing design files, fabrication workflow for JLCPCB, and revision management.
    - Documented companion repositories for firmware and client libraries.
    [brushed_motors_and_encoders.kicad_sch, power.kicad_sch, smart_motor_controller-BOM.csv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]
2026-07-11 Initial changes
    [IMU.kicad_sch, brushed_motors_and_encoders.kicad_sch, encoders.kicad_sch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]
2026-08-02 Add USB sensing and power management components to the schematic
    - Introduced a junction for USB sensing at coordinates (173.99, 64.77).
    - Added multiple wires connecting various components to the new junction.
    - Created a global label "USB_SENSE" for the USB sensing functionality.
    - Updated references for power components to a new numbering scheme (#PWR0501 to #PWR0509).
    - Added resistors R505 and R506 with specified values and footprints.
    - Included power symbols for +5V and GND with appropriate references and properties.
    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
    [IMU.kicad_sch, brushed_motors_and_encoders.kicad_sch, encoders.kicad_sch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]
2026-08-31 Implement structure for code changes tracking
    [IMU.kicad_sch, smart_motor_controller.kicad_pcb, smart_motor_controller.kicad_sch]
